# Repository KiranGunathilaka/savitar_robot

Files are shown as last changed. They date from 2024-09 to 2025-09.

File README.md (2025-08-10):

# Savitar Bot
## Compilations of Videos we had taken
[Youtube](https://youtu.be/TuMXFdOwjP4)

## Codebase
[Savitar Robot Codebase](https://github.com/KiranGunathilaka/savitar_robot_codebase)

## Robot Architeture
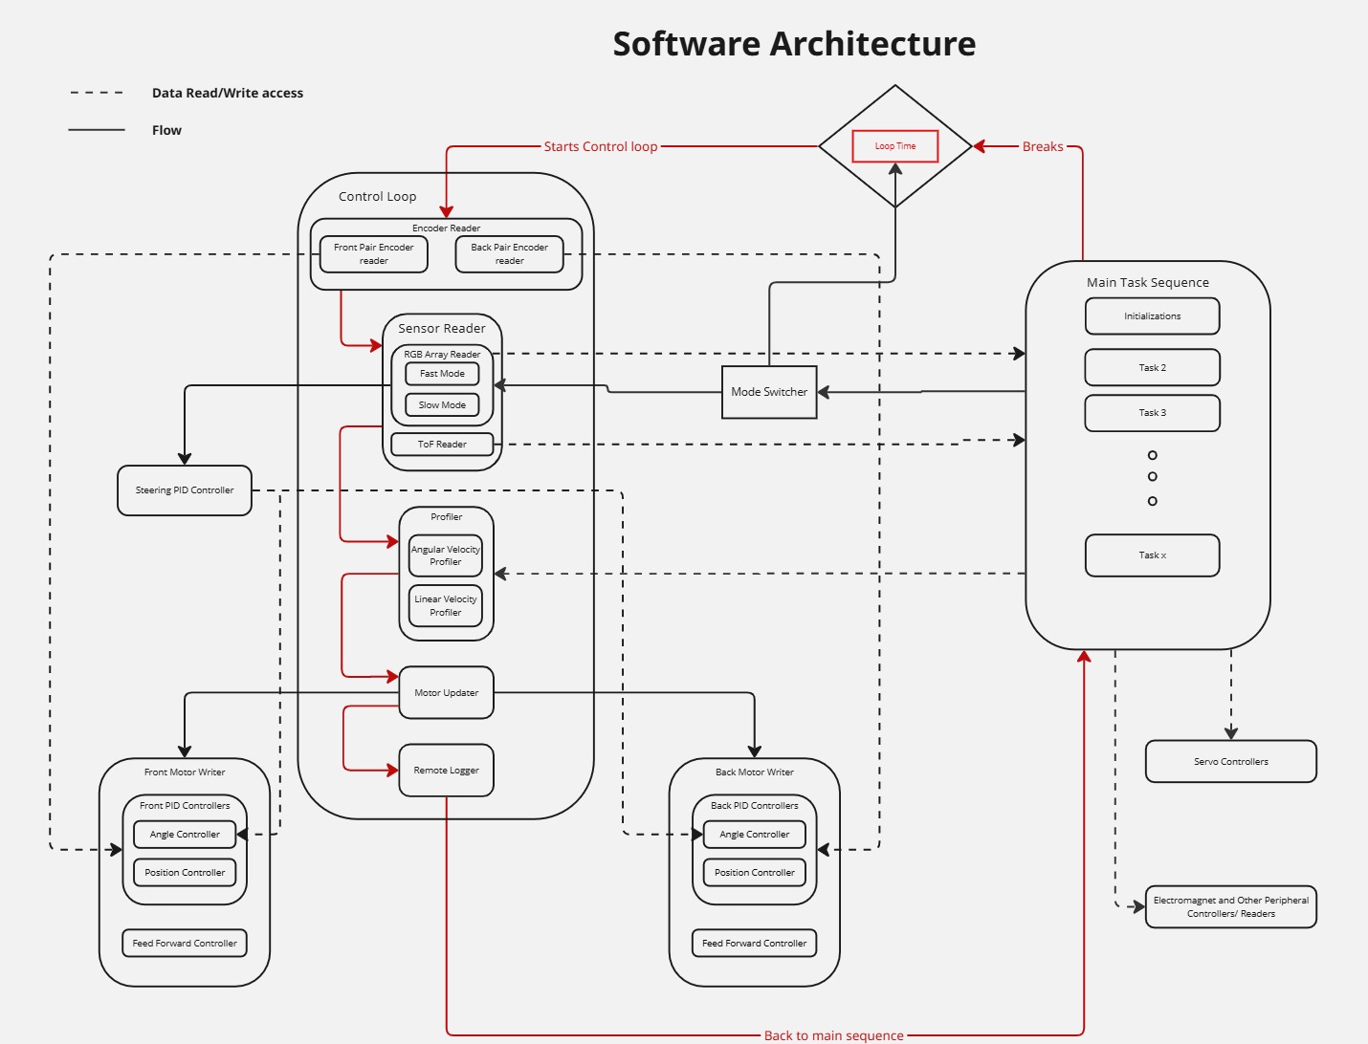
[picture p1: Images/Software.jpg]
Savitar Software

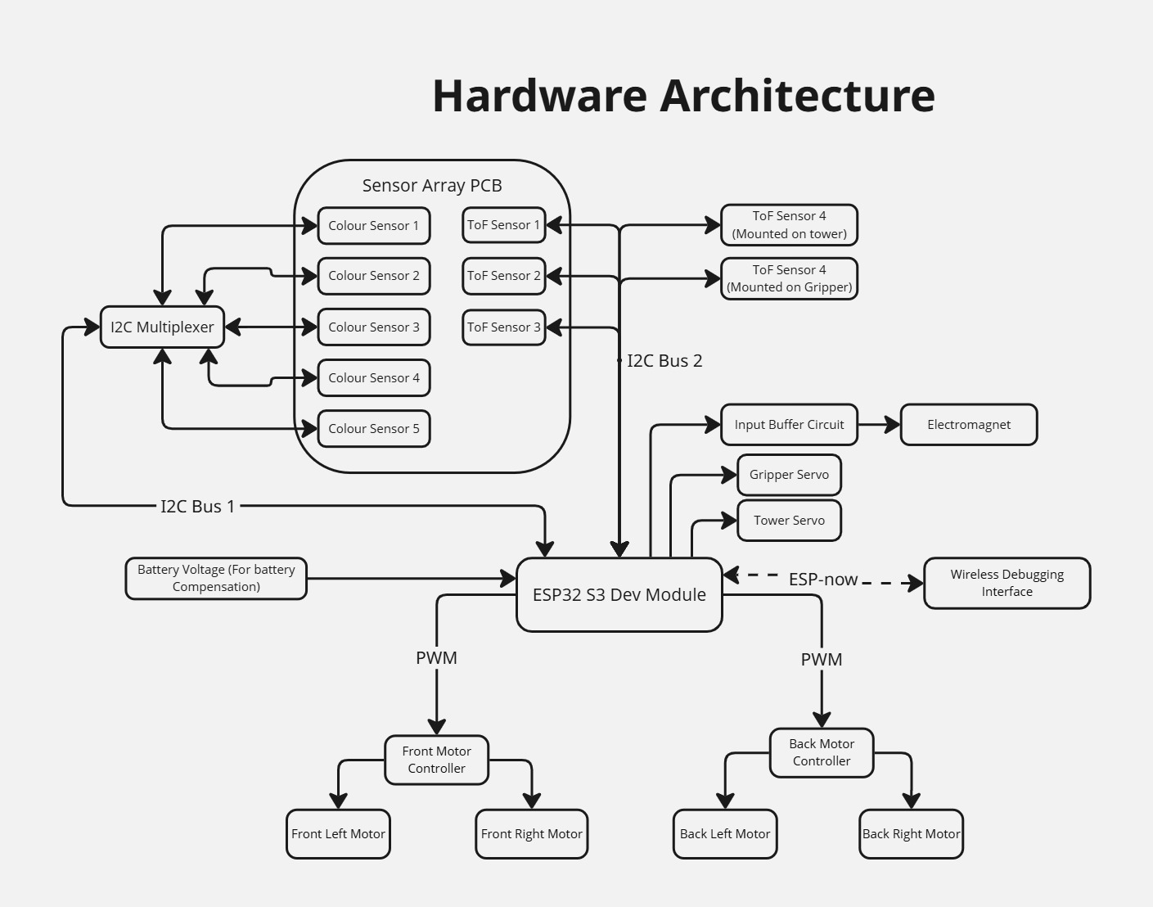
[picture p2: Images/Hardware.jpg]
Savitar Hardware


## Motor Responses
These were done to get the motor function between rps and pwm percentage that need to be fed for feed forward control.
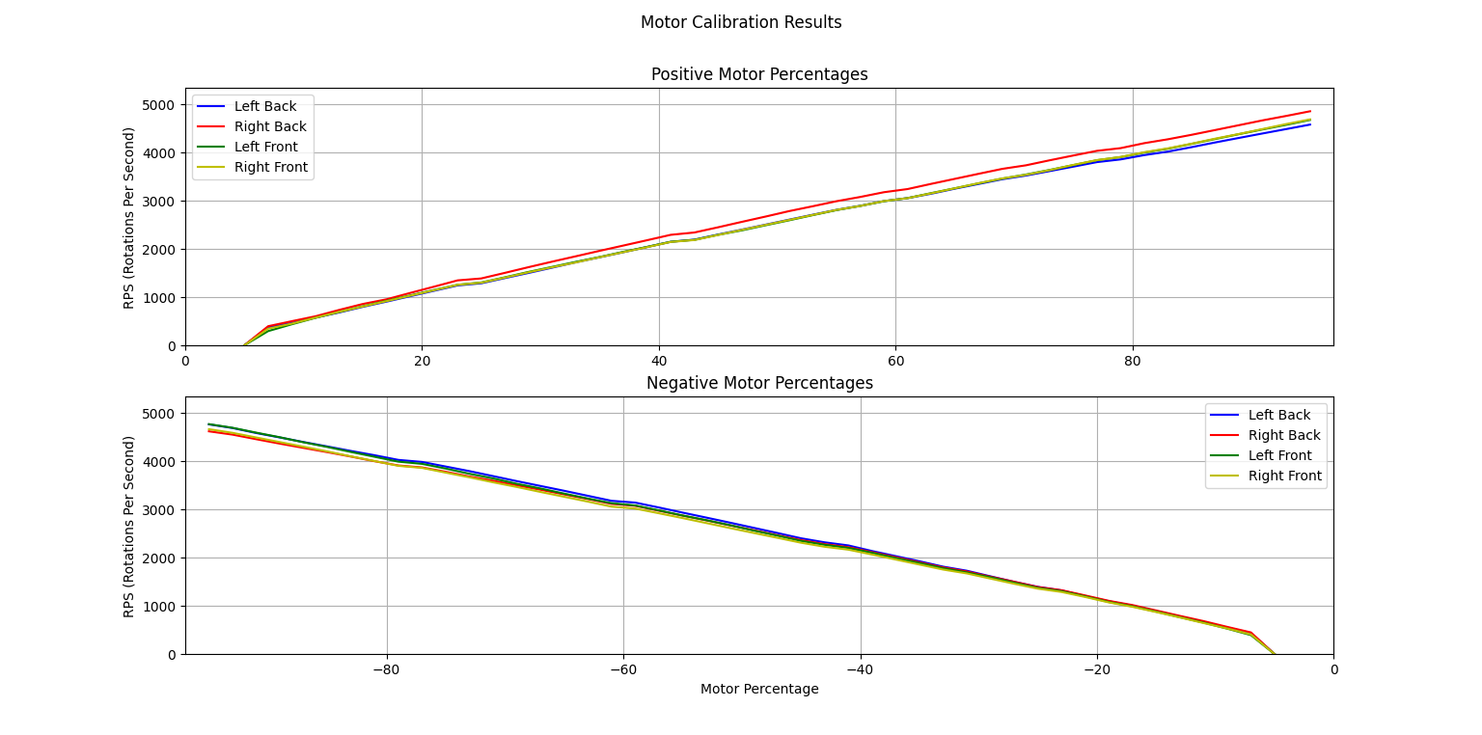
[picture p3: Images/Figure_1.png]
Motor Functions


All the motor logs are available here. 
[Codebase/Test](https://github.com/KiranGunathilaka/savitar_robot_codebase/tree/main/test/motor_logs)

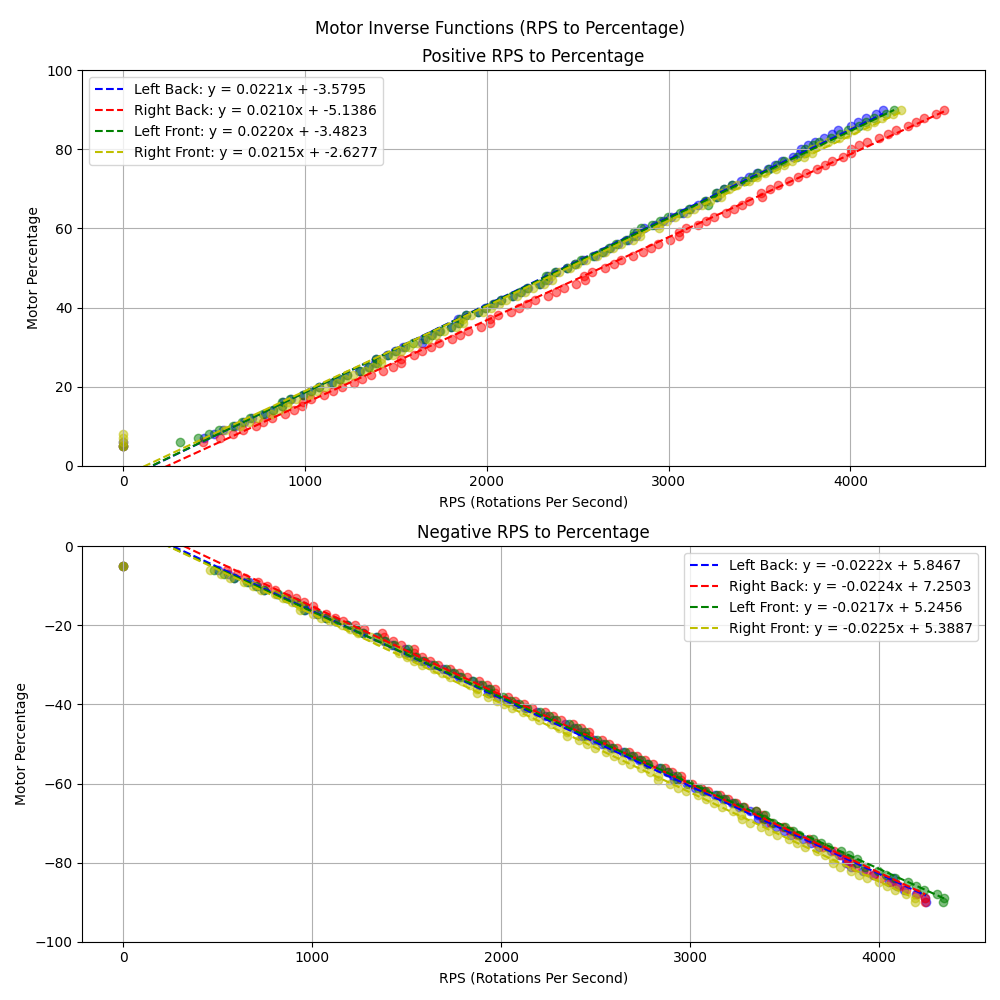
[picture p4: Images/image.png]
Inverse functions


## PCB
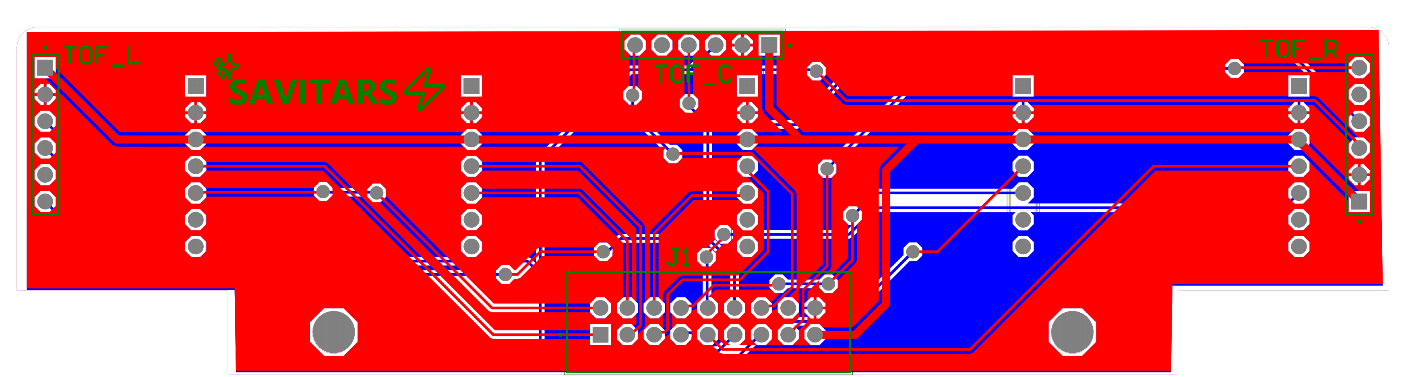
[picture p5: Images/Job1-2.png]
2D View

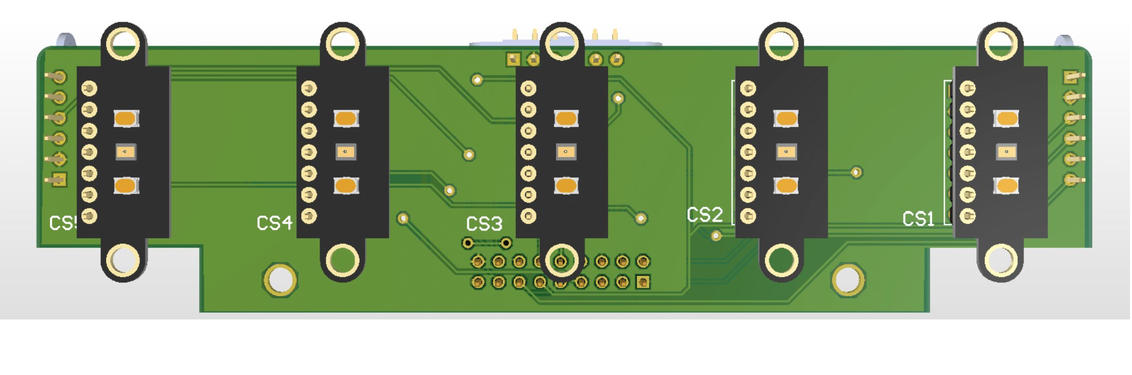
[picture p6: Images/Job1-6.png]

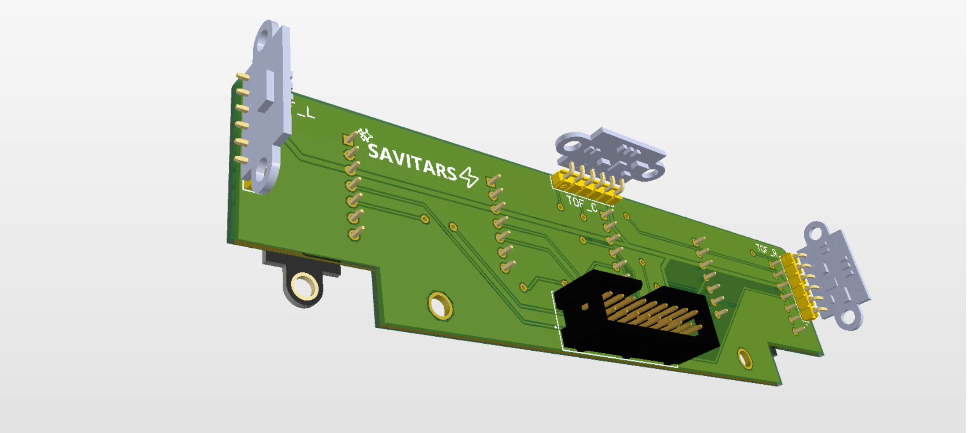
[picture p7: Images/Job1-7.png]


## CAD Designs
### Design V3
Tested and final printed design
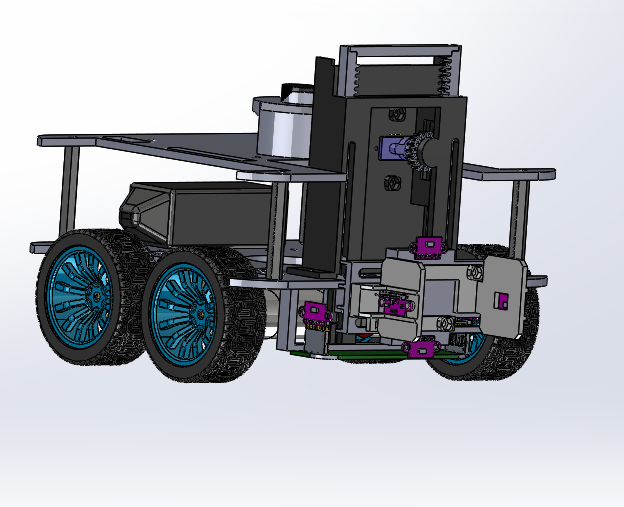
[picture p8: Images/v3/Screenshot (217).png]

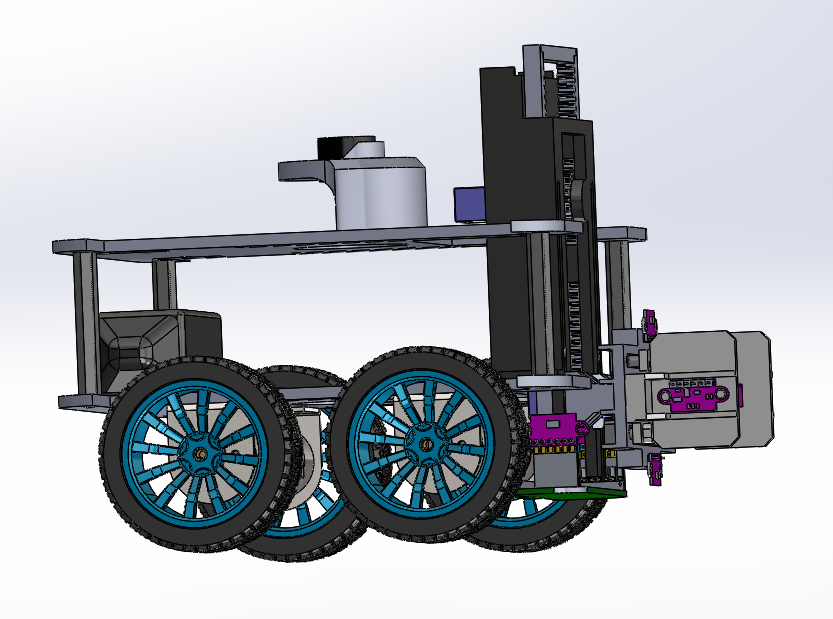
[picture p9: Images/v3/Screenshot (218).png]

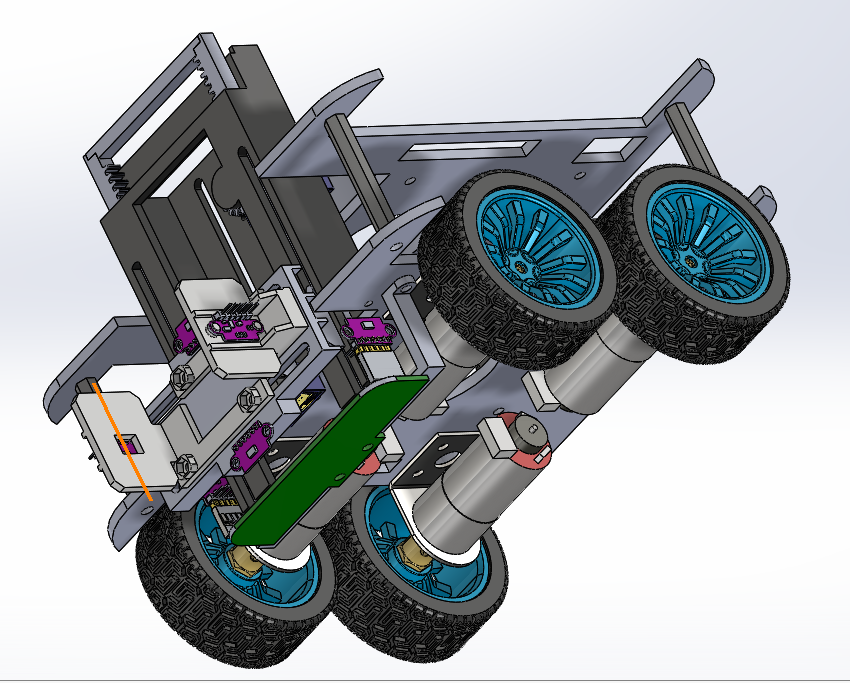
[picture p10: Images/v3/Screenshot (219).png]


## Previous Designs
### Design V1
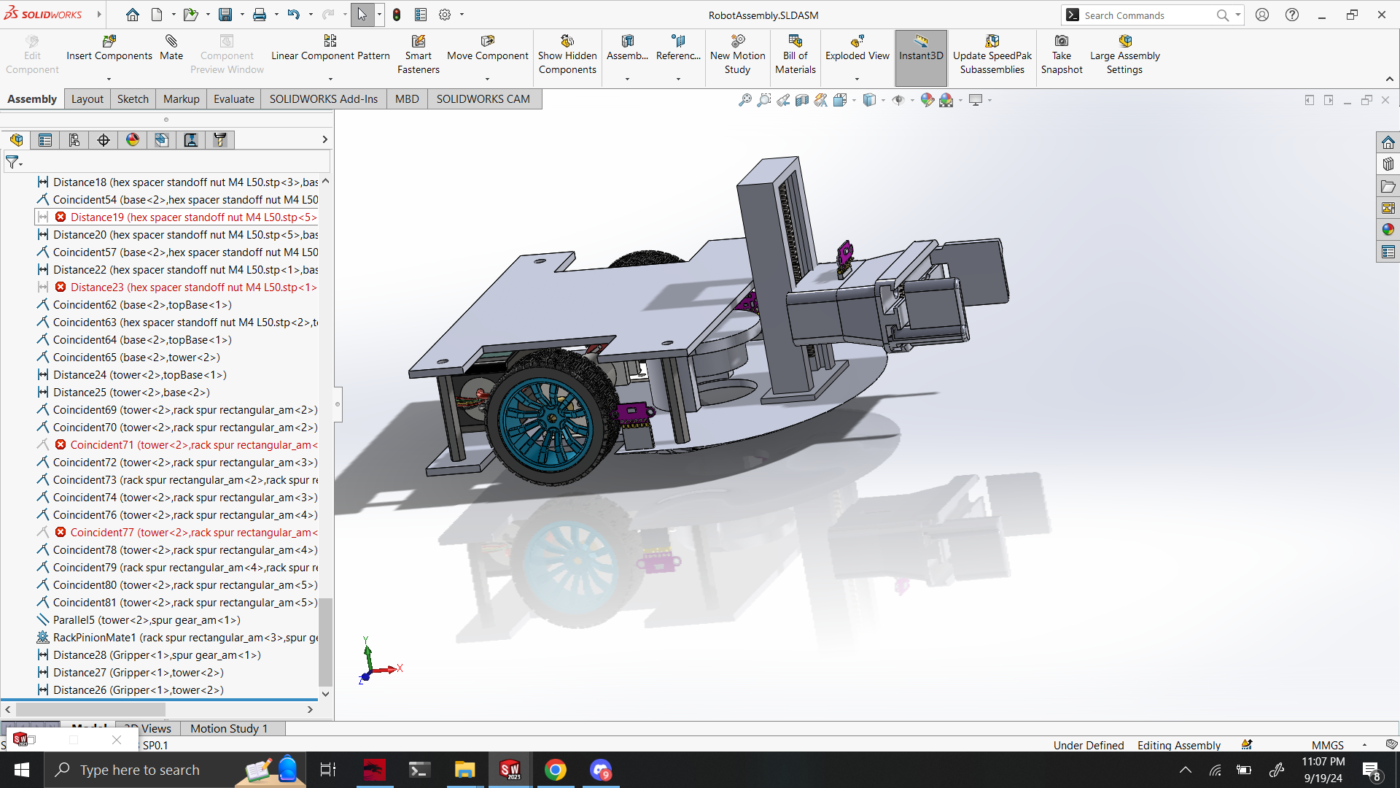
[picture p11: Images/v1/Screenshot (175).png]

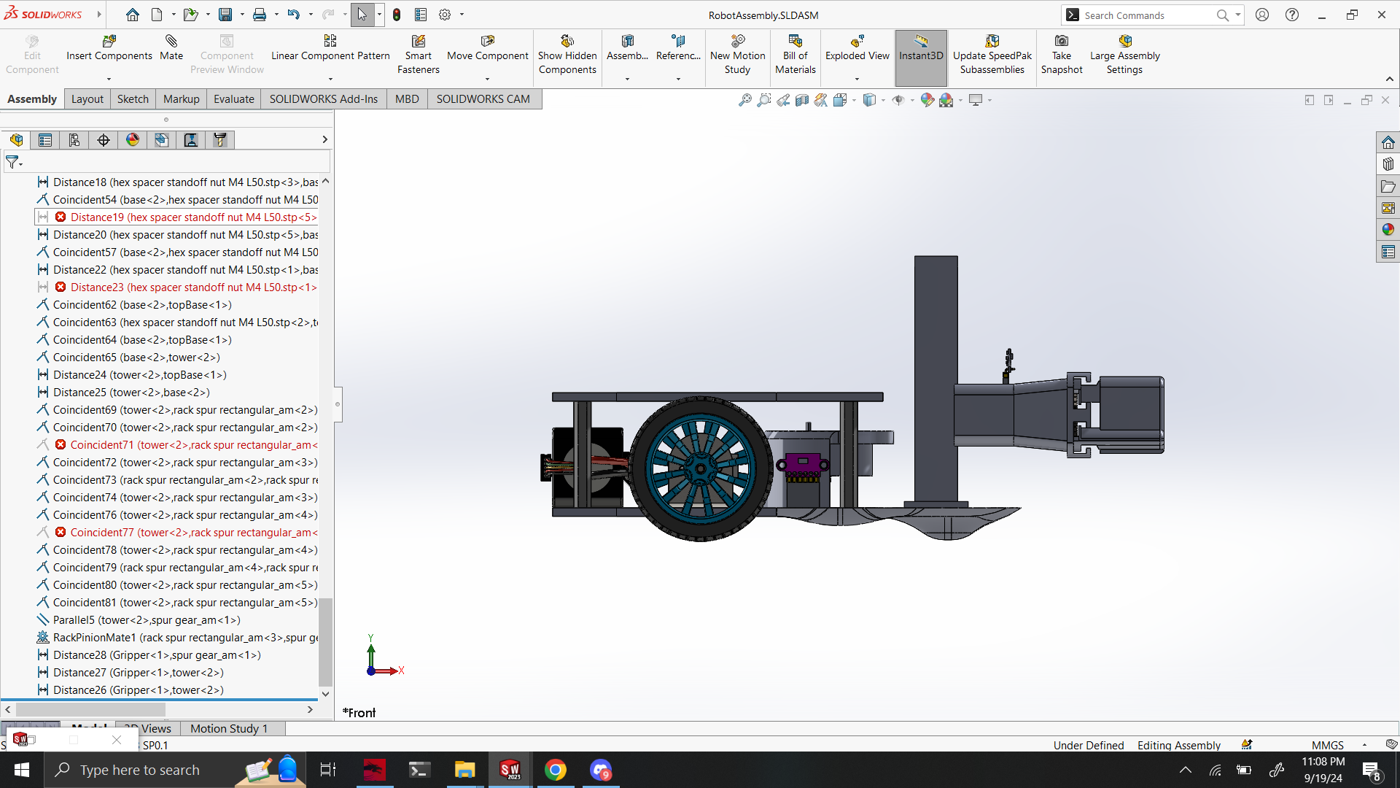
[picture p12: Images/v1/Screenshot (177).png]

### Design V2
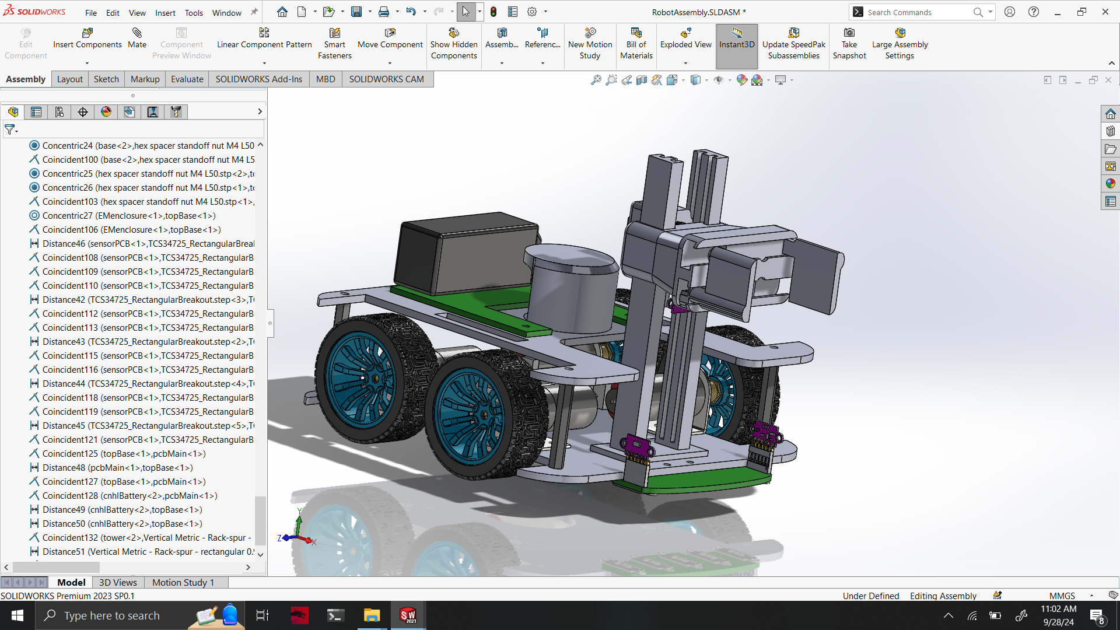
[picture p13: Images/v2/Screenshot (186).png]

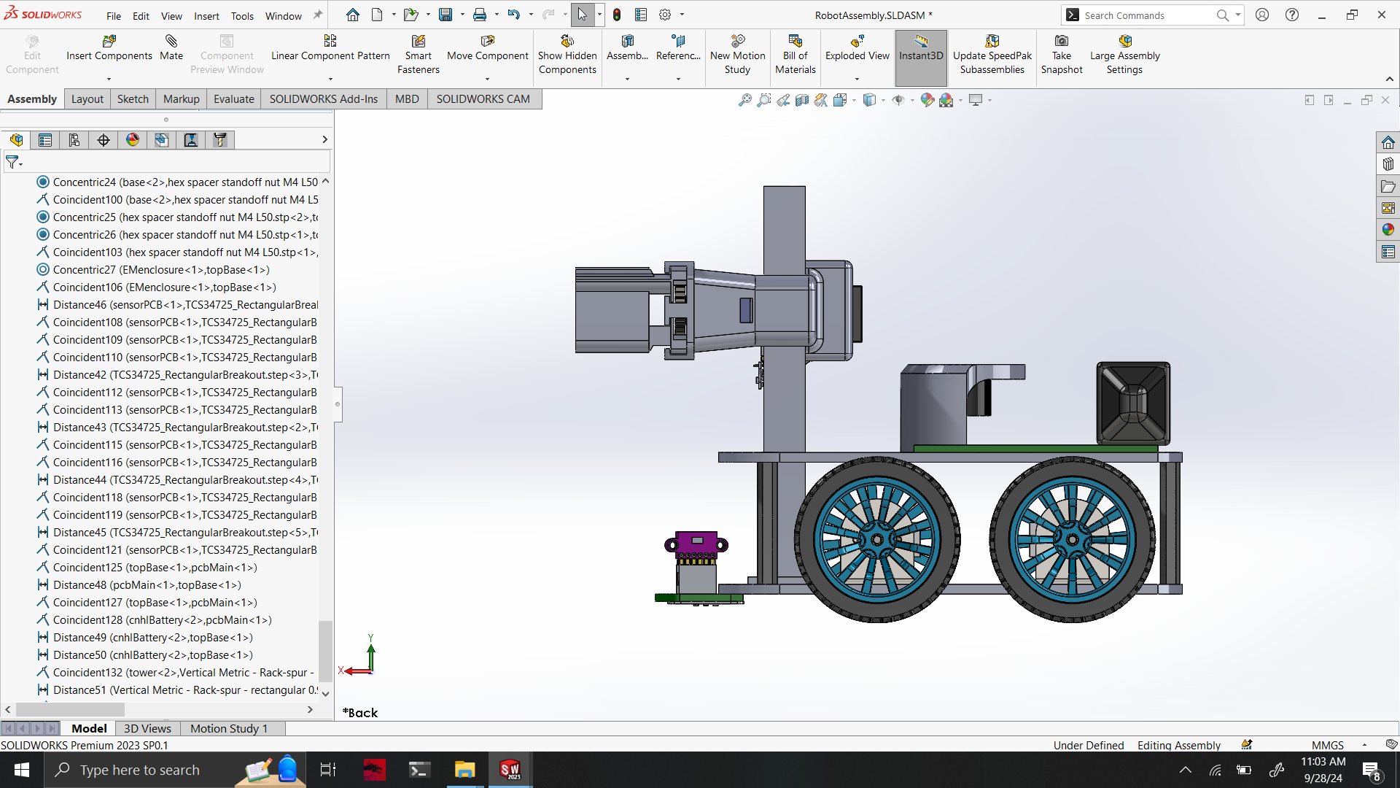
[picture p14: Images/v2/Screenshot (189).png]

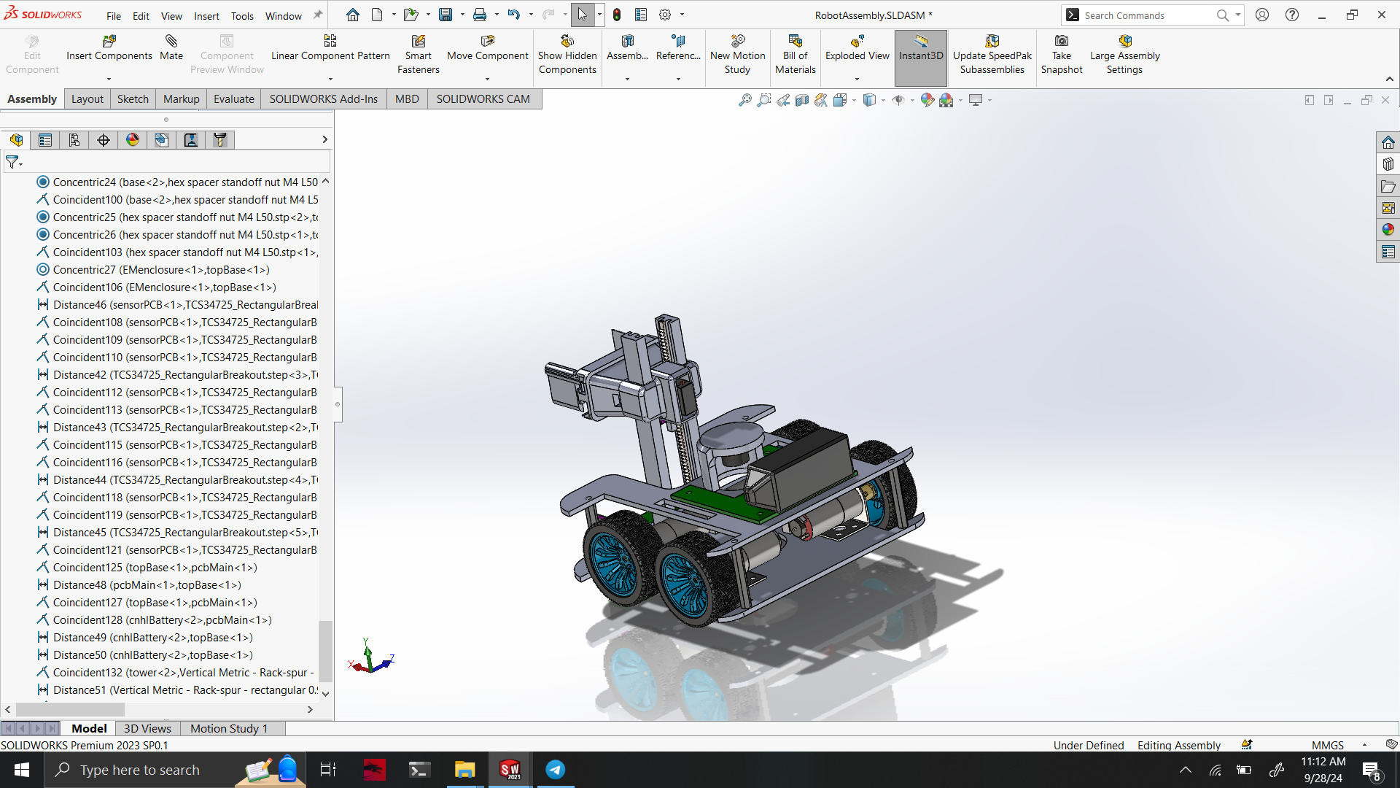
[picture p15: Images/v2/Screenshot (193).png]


### This is the codebase. Full repo is at [Here](https://github.com/KiranGunathilaka/savitar_robot)

<div style="background:#ffffff; color:#111; padding:18px; border-radius:12px; box-shadow:0 2px 10px rgba(0,0,0,.06); font-family:system-ui,-apple-system,Segoe UI,Roboto,Arial,sans-serif; line-height:1.6;">

  <h1 style="margin:0 0 8px;">⚡ Savitar Robot — ESP32-S3 Modular Control Stack</h1>
  <p style="margin:0 0 10px;">
    <strong>Savitar</strong> is a four-motor mobile robot with an <strong>ESP32-S3</strong> brain, color &amp; ToF sensing, a two-pair
    differential drivetrain, and on-the-fly retimed control loops. The firmware is a <strong>PlatformIO</strong> C++ codebase with clean
    separation of <em>motors</em>, <em>motion</em>, <em>sensors</em>, <em>loop scheduling</em>, and <em>telemetry</em>.
  </p>

  <div style="display:flex; gap:12px; flex-wrap:wrap; margin:8px 0 12px;">
    <div style="flex:1; min-width:260px; padding:10px 12px; border:1px solid #e5e7eb; background:#fafafa; border-radius:10px;">
      <strong>Repos</strong>
      <ul style="margin:6px 0 0 18px;">
        <li><a href="https://github.com/KiranGunathilaka/savitar_robot" target="_blank" rel="noopener" style="color:#0b5; text-decoration:none;">github.com</a></li>
        <li>Motor logs: <a href="https://github.com/KiranGunathilaka/savitar_robot_codebase/tree/main/test/motor_logs" target="_blank" rel="noopener">/test/motor_logs</a></li>
      </ul>
    </div>
    <div style="flex:1; min-width:260px; padding:10px 12px; border:1px solid #e5e7eb; background:#fafafa; border-radius:10px;">
      <strong>Video</strong>
      <div style="position:relative; padding-bottom:56.25%; height:0; overflow:hidden; border-radius:8px; border:1px solid #e5e7eb; margin-top:8px;">
        <iframe src="https://www.youtube.com/embed/TuMXFdOwjP4" title="Savitar robot compilation" style="position:absolute; inset:0; width:100%; height:100%; border:0;" allow="accelerometer; autoplay; clipboard-write; encrypted-media; gyroscope; picture-in-picture; web-share" allowfullscreen></iframe>
      </div>
    </div>
  </div>

  <!-- Architecture images -->
  <div style="display:grid; grid-template-columns:repeat(auto-fit,minmax(260px,1fr)); gap:12px; margin:10px 0 12px;">
    <a href="https://raw.githubusercontent.com/KiranGunathilaka/savitar_robot/main/Images/Software.jpg" target="_blank" rel="noopener">
      Software architecture
    </a>
    <a href="https://raw.githubusercontent.com/KiranGunathilaka/savitar_robot/main/Images/Hardware.jpg" target="_blank" rel="noopener">
      Hardware architecture
    </a>
  </div>

  <hr style="border:none; border-top:1px solid #e5e7eb; margin:12px 0;">

  <h2 style="margin:0 0 8px;">🧭 High-Level Design</h2>
  <ul style="margin:0 0 10px 18px;">
    <li><strong>Two independent closed-loop differential pairs</strong> (front &amp; back), each with its own encoder PID and <em>feed-forward</em>, unified by a higher-layer <strong>Motion</strong> controller for v/ω profiles and turning.</li>
    <li><strong>Two line-follow modes</strong> with <em>dynamic control-loop timings</em>:
      <ul style="margin:6px 0 0 18px;">
        <li><strong>FAST_MODE</strong> (black/white tracking) → control loop at <strong>FAST_TICKER</strong> <em>(currently 25&nbsp;ms)</em>.</li>
        <li><strong>SLOW_MODE</strong> (4-color discrimination) → loop at <strong>SLOW_TICKER</strong> <em>(currently 60&nbsp;ms)</em>.</li>
      </ul>
      Mode switching happens on-the-fly: the ticker retimes and the sensor sampler swaps integration windows without rebooting the stack.
    </li>
    <li><strong>ESP-NOW telemetry & tuning</strong>: logs (RGB/ToF/odometry/servo) are broadcast; updated gains/params can be injected from a paired controller.</li>
  </ul>

  <h2 style="margin:0 0 8px;">🧩 Firmware Modules</h2>
    <div style="flex:1; min-width:260px; border:1px solid #e5e7eb; border-radius:10px;">
      <div style="padding:10px 12px; background:#fafafa; border-bottom:1px solid #e5e7eb;"><strong>Motors</strong></div>
      <div style="padding:10px 12px;">
        <ul style="margin:0 0 8px 18px;">
          <li>Maintains <strong>independent PID state</strong> (FWD/ROT) for <em>front</em> and <em>back</em> pairs.</li>
          <li>Applies <strong>feed-forward</strong> models (derived from rps↔PWM calibration) per wheel; accounts for <em>battery sag</em> using measured voltage.</li>
          <li>Combines translational &amp; rotational commands → per-wheel PWM via IN1/IN2/PWM pins (polarity configurable).</li>
        </ul>
        <small style="color:#555;">KP/KD sets present for front/back, with per-wheel polarity and PWM channels.</small>
      </div>
    </div>
    <div style="flex:1; min-width:260px; border:1px solid #e5e7eb; border-radius:10px;">
      <div style="padding:10px 12px; background:#fafafa; border-bottom:1px solid #e5e7eb;"><strong>Motion</strong></div>
      <div style="padding:10px 12px;">
        <ul style="margin:0 0 8px 18px;">
          <li>Holds <strong>linear</strong> and <strong>angular</strong> motion profiles with slew/accel limits.</li>
          <li>Resets/advances profiles each tick; emits unified v/ω setpoints into <em>Motors</em>.</li>
        </ul>
      </div>
    </div>
    <div style="flex:1; min-width:260px; border:1px solid #e5e7eb; border-radius:10px;">
      <div style="padding:10px 12px; background:#fafafa; border-bottom:1px solid #e5e7eb;"><strong>Sensors</strong></div>
      <div style="padding:10px 12px;">
        <ul style="margin:0 0 8px 18px;">
          <li>RGB array via <strong>I²C multiplexer</strong> (TCS34725). Switches integration window based on mode.</li>
          <li>ToF sensors (front/left/right/center-top/center-bottom) with XSHUT pin control and custom addresses.</li>
          <li>Computes steering error using <em>SENSOR_WEIGHTS</em>; classifies <strong>white / red / blue / black / unknown</strong>.</li>
        </ul>
      </div>
    </div>
    <div style="flex:1; min-width:260px; border:1px solid #e5e7eb; border-radius:10px;">
      <div style="padding:10px 12px; background:#fafafa; border-bottom:1px solid #e5e7eb;"><strong>Systick &amp; Robot</strong></div>
      <div style="padding:10px 12px;">
        <ul style="margin:0 0 8px 18px;">
          <li><strong>Systick</strong> ticker calls encoders → sensors → motion → motors at <em>FAST_TICKER</em>/<em>SLOW_TICKER</em>.</li>
          <li><code>enableSlowMode()</code> retimes the loop and flips sensor mode dynamically.</li>
          <li><strong>Robot</strong> orchestrates the flow (e.g., barcode read, maze steps), commanding sensor modes and motion sequence.</li>
        </ul>
      </div>
    </div>
    <div style="flex:1; min-width:260px; border:1px solid #e5e7eb; border-radius:10px;">
      <div style="padding:10px 12px; background:#fafafa; border-bottom:1px solid #e5e7eb;"><strong>Reporting</strong></div>
      <div style="padding:10px 12px;">
        <ul style="margin:0 0 8px 18px;">
          <li>Packs color/ToF/odometry/servo state into ESP-NOW frames to a paired MAC.</li>
          <li>Receives updated gains &amp; parameters for in-field tuning.</li>
        </ul>
      </div>
    </div>

  <h2 style="margin:14px 0 8px;">🔧 Hardware & Config Highlights</h2>
  <div style="display:grid; grid-template-columns:repeat(auto-fit,minmax(260px,1fr)); gap:12px;">
    <div style="border:1px solid #e5e7eb; border-radius:10px; padding:10px 12px;">
      <strong>Drivetrain & Encoders</strong>
      <ul style="margin:6px 0 0 18px;">
        <li><em>4 encoders</em> (LF: 18/8, LB: 3/46, RF: 48/45, RB: 35/36), <em>PULSES_PER_ROTATION</em>=1495.</li>
        <li>Wheel Ø (front/back): 63&nbsp;mm, wheel gap: 189.5&nbsp;mm → <em>DEG_PER_MM_DIFFERENCE</em> derived.</li>
        <li>PWM channels: LF=2, RF=3, LB=4, RB=5; polarity defines forward sense per wheel.</li>
      </ul>
    </div>
    <div style="border:1px solid #e5e7eb; border-radius:10px; padding:10px 12px;">
      <strong>PID & FF</strong>
      <ul style="margin:6px 0 0 18px;">
        <li>Back: FWD KP/KD = 1.0/0.5, ROT KP/KD = 9.18/0.229.</li>
        <li>Front: FWD KP/KD = 1.0/0.5, ROT KP/KD = 9.18/0.229.</li>
        <li>Bias/limits: MIN_BIAS=13, MAX_MOTOR_PERCENT=90, dead-zone floor=5%.</li>
      </ul>
    </div>
    <div style="border:1px solid #e5e7eb; border-radius:10px; padding:10px 12px;">
      <strong>Sensing</strong>
      <ul style="margin:6px 0 0 18px;">
        <li>I²C0: SDA=19, SCL=20 · I²C1: SDA=21, SCL=47.</li>
        <li>RGB sensor (TCS34725) via mux 0x70; fast/slow integration presets.</li>
        <li>ToF XSHUT: R=11, L=13, F=12, CT=10, CB=9 · I²C addrs: 0x30–0x34.</li>
        <li>Steering gains (RGB): KP=14.0, KD=5.5; weights: {2,1,0,-1,-2}.</li>
      </ul>
    </div>
    <div style="border:1px solid #e5e7eb; border-radius:10px; padding:10px 12px;">
      <strong>System & IO</strong>
      <ul style="margin:6px 0 0 18px;">
        <li>FAST_TICKER=0.025&nbsp;s · SLOW_TICKER=0.060&nbsp;s (retimed by mode).</li>
        <li>Servos: gripper=38 (0→140°), lift=14; EM pin=41; user switch=7; LED=0.</li>
        <li>ESP-NOW peer MAC baked in (<code>broadcastAddress</code>).</li>
      </ul>
    </div>
  </div>

  <h2 style="margin:14px 0 8px;">📈 Motor Characterization & Feed-Forward</h2>
  <p style="margin:0 0 8px;">Each motor was profiled to establish rps↔PWM relationships for feed-forward terms; this reduces PID effort and keeps response consistent across loads/voltage.</p>
  <div style="display:grid; grid-template-columns:repeat(auto-fit,minmax(260px,1fr)); gap:12px;">
    <a href="https://raw.githubusercontent.com/KiranGunathilaka/savitar_robot/main/Images/Figure_1.png" target="_blank" rel="noopener">
      Motor functions (rps vs PWM)
    </a>
    <a href="https://raw.githubusercontent.com/KiranGunathilaka/savitar_robot/main/Images/image.png" target="_blank" rel="noopener">
      Inverse functions
    </a>
  </div>
  <p style="margin:6px 0 12px;">Logs & CSVs for these curves are available in <a href="https://github.com/KiranGunathilaka/savitar_robot_codebase/tree/main/test/motor_logs" target="_blank" rel="noopener">test/motor_logs</a>.</p>

  <h2 style="margin:14px 0 8px;">🛠️ Build & Calibrate (high-level)</h2>
  <ol style="margin:0 0 10px 18px;">
    <li>Open the repo in <strong>PlatformIO</strong> and select the ESP32-S3 environment.</li>
    <li>Wire up encoders/motors/sensors per <em>configuration header</em> (pins & addresses above).</li>
    <li>Upload, verify encoder counts, then run motor characterization if you change the drivetrain.</li>
    <li>Calibrate RGB sensors (white/black &amp; colors) and ToF offsets; save constants.</li>
    <li>Test <strong>FAST_MODE</strong> and <strong>SLOW_MODE</strong> switching; check loop timing histograms in ESP-NOW logs.</li>
  </ol>

  <h2 style="margin:0 0 8px;">🚀 Notes & Next Steps</h2>
  <ul style="margin:0 0 4px 18px;">
    <li>Add loop-overrun counters and a small timing histogram to the logger.</li>
    <li>Store per-mode PID/FF presets with bumpless transfer on retime.</li>
    <li>Extend obstacle handling (wall following & ToF fusion) with a small EKF for heading drift.</li>
  </ul>

</div>

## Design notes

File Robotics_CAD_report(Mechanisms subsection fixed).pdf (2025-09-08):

# Initial Prototype of the Mobile Robot-CAD drawings

### Group name : Savitars

Group Members : K.L.Gunathilaka (220197E), I.J.M.J. Sadaruwan(220542J), L.P.P. Pahasara (220439B), T.P.N.S. Peiris (220454P), M.P.L. Budvin (220077L)

## 1 Overview

This report outlines the preliminary design of our robotic system .The core components such as motors,sensors,and modules will be taken from existing manufacturers, while the remaining structural and functional elements are designed by ourselves.To facilitate the development process, CAD drawings have been created to visualize the overall mechanical design and dimensions of the robot. To ensure flexibility and efficieny,we are planning to design a custom PCB for the system therefore the specific placement of motor drivers and microcontrollers are not specifically mentioned in this report.

## 2 Robot Layout

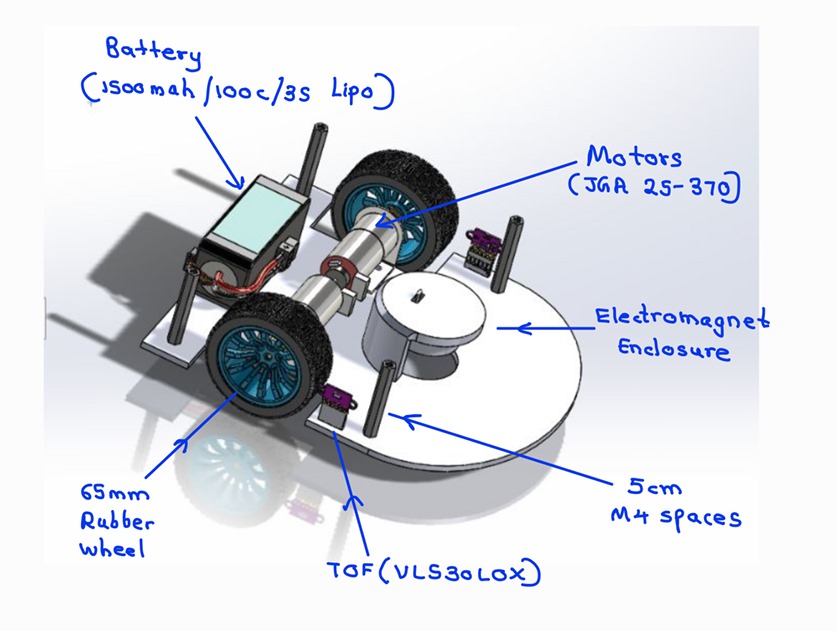
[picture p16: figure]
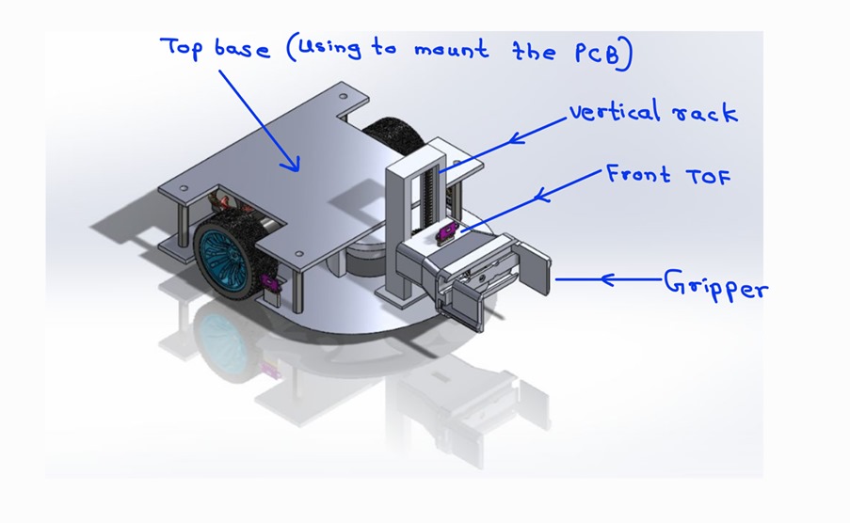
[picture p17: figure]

Figure 1 | Figure 2

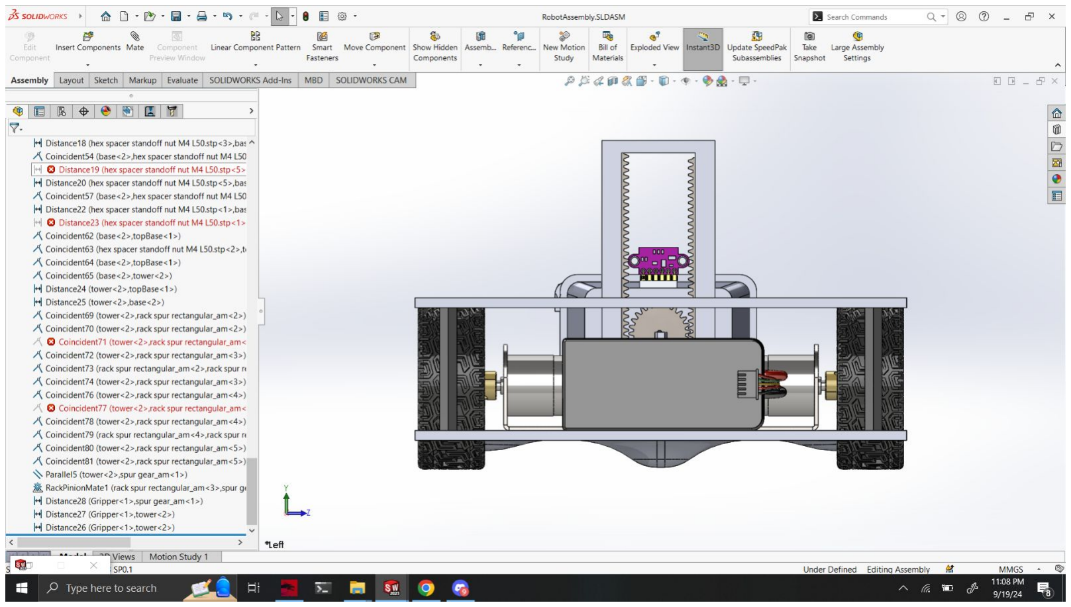
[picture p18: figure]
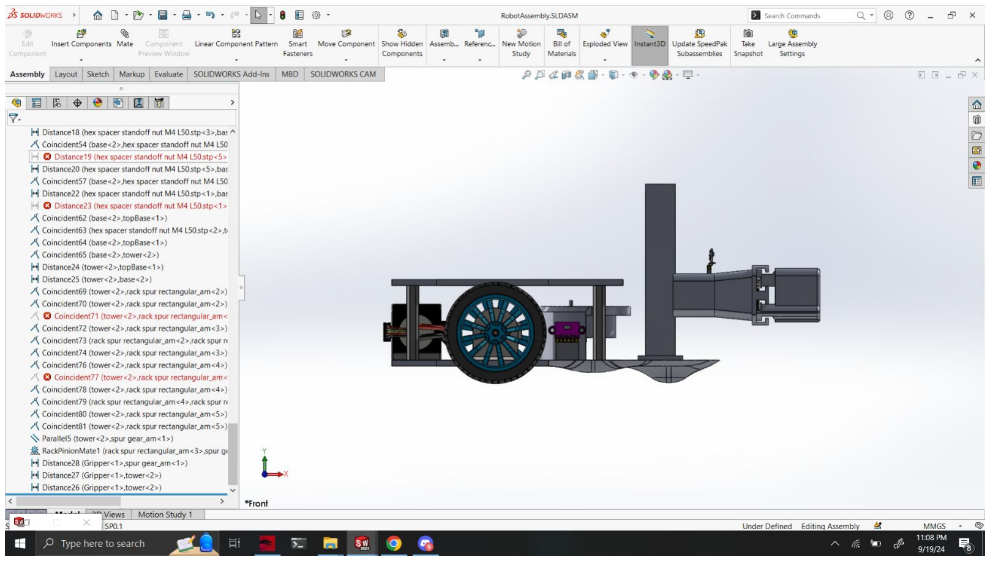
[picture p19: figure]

Figure 3: Front View | Figure 4: Side View

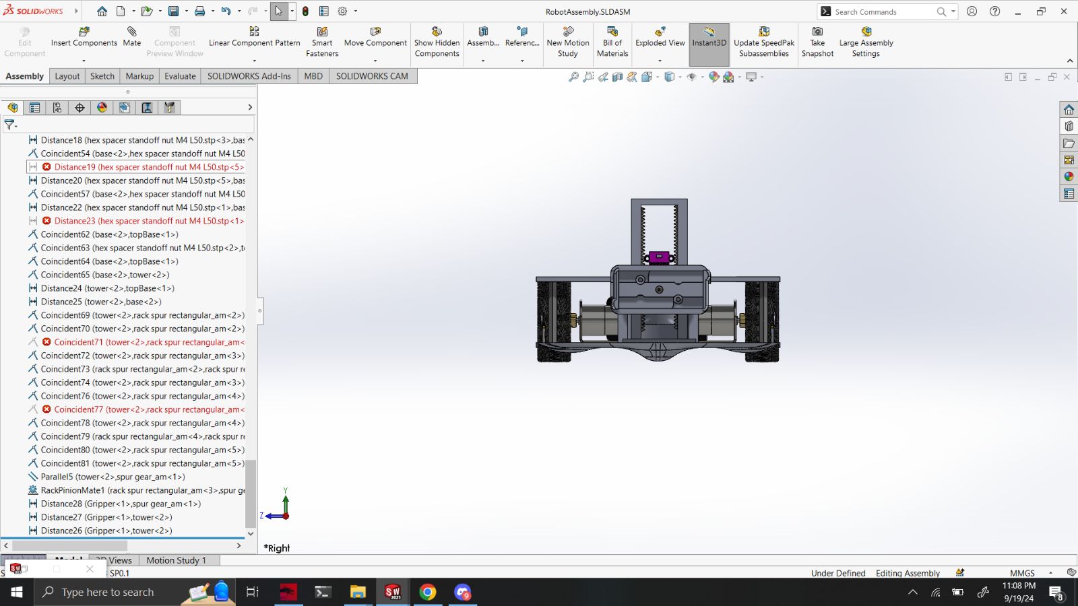
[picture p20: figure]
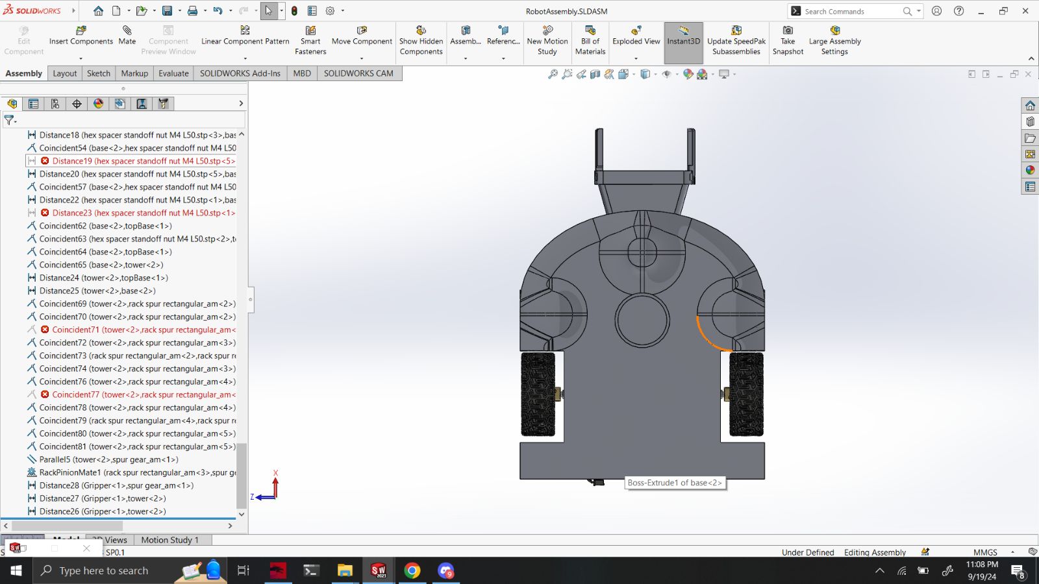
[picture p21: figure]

Figure 5: Rear View | Figure 6: Bottom Veiw

## 3 Actuator Mechanisms

### 3.1 Gripper Mechanism

The robot will utilize rack and pinion mechanism for its parallel gripper.The gripper has a very small thickness of only 4mm, enabling it to navigate tight spaces.With a maximum opening of 6.9cm, the gripper can grasp the 5cm box which is ideal for our purposes. Even while holding the box the combined width of the gripper arm (4mm) and the grasped box (5cm) adds up to 5.8cm, leaving enough space to pass through the 7cm x 7cm chamber opening.

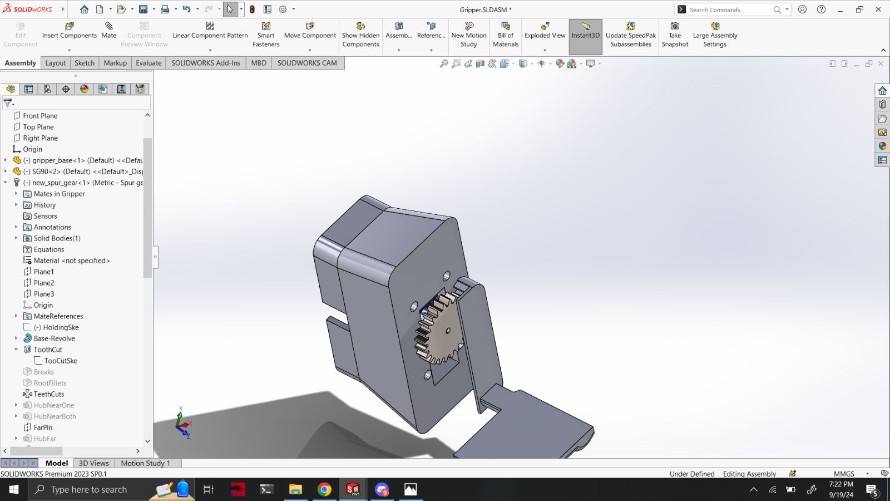
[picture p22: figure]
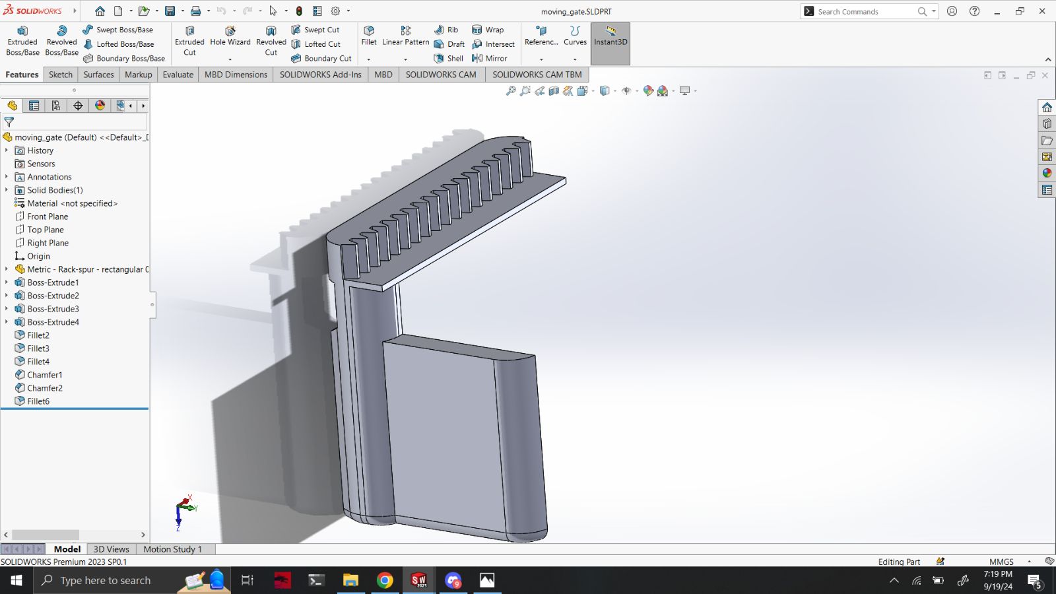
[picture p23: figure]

(a) Pinion | (b) Rack

### 3.2 Vertical rack and pinion mechanism

### 3.2.1 Box Height Detection

The gripper has a vertical range of motion, allowing it to move up and down to identify boxes of 5cm, 10cm, and 15cm.This gripper has a vertical range of 2.5cm to 12.5cm.

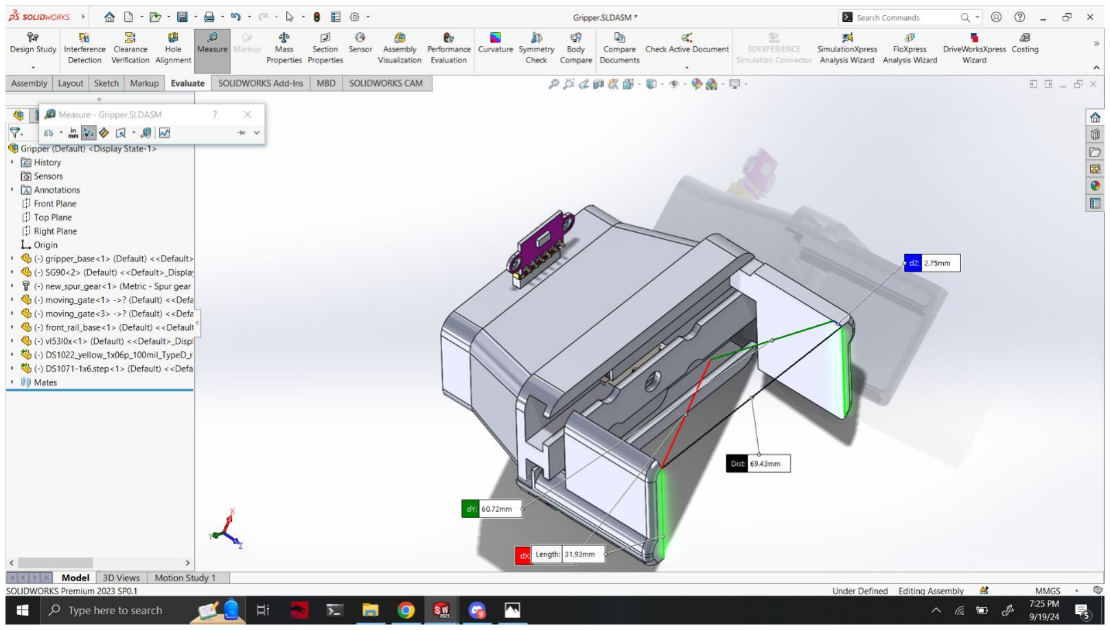
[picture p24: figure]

Figure 8: Front ToF mounted on the gripper for detecting height

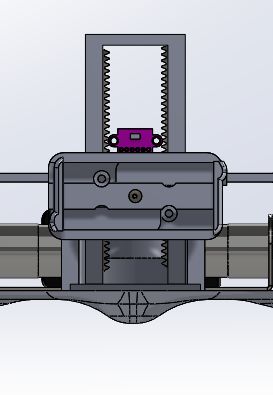
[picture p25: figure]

Figure 9: Gripper is free to slide on the vertical rack

### 3.2.2 Moving Boxes Vertically

The robot will pick up the boxes and lift them 5cm high using the gripper before placing them in the destination.

### 3.3 Coin Drop Mechanism

The robot will use a electromagnet to securely hold the coin.Once the robot reaches the designated drop point, a KK P20/15 3kg solenoid (selected locally available electromagnet) will be de-energized, releasing the coin from the gripper’s magnetic hold. This controlled release ensures that the coin falls gently and accurately at the intended location.

## 4 Robot Base

The base is positioned 11mm above the ground.During line-following and other tasks, only the front center of the base makes contact with the ground, providing precise control.To enhance stability and prevent tipping on uneven terrain, two additional contact points are located on the sides of the base, each measuring 8mm.These side contact points ensure that the robot remains firmly grounded.We have already tested a similar base for another application in the past.

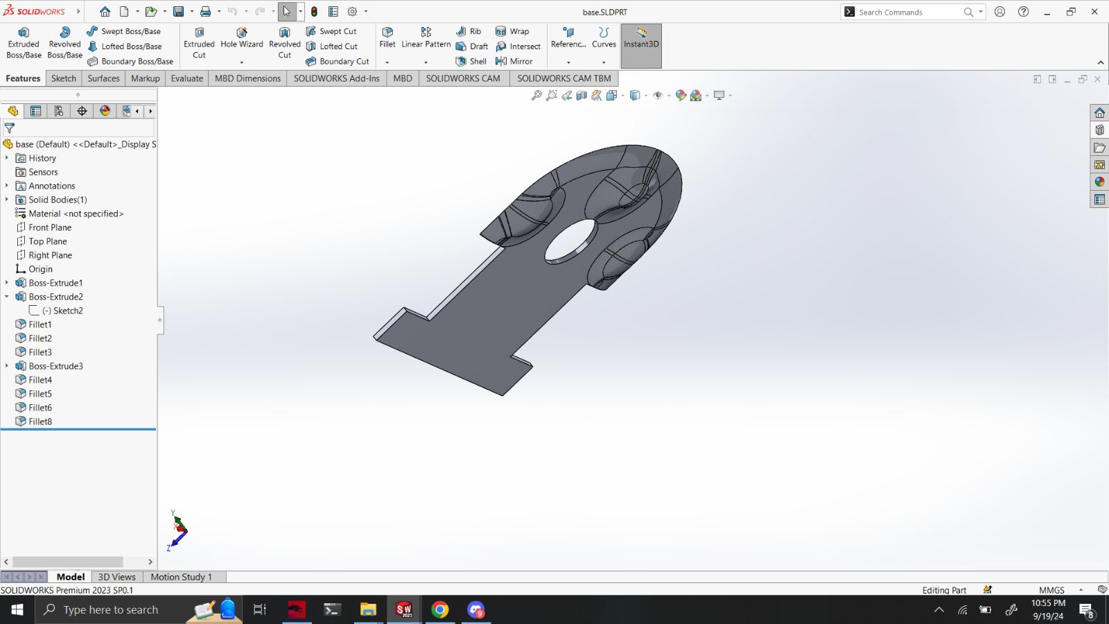
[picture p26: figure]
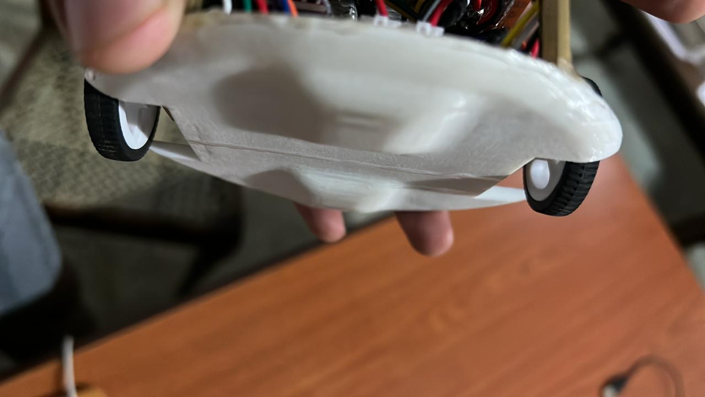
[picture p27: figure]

Figure 10 | Figure 11

## 5 Actuators

### 5.1 MG90 Servo Motor

The MG90 servo motor will be used to drive the gripper across the vertical rack. MG90 was specifically selected for this purpose because it has torque of 2.2kg/cm and will be capable of lifting both the boxes and the gripper

### 5.2 SG90 Servor Motor

SG90 servo will be used to open and close robot’s parralel gripper arms throuth the rack and pinion mechanism. We have selected this servo as this appication does not require much torque as the servo needed for hoisting the gripper and the boxes.

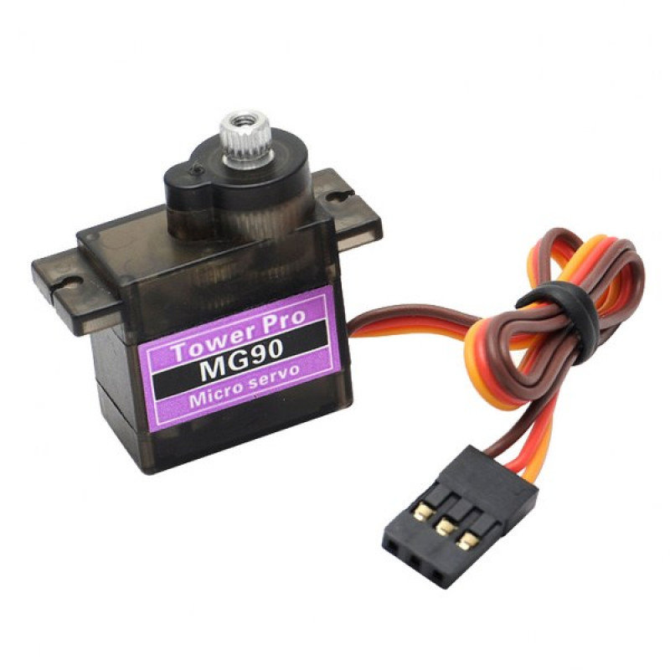
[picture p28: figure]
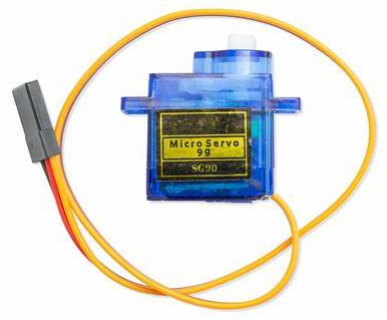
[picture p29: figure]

Figure 12: MG90 | Figure 13: SG90

Both the servos might need to be modified to do the 360 degree rotation by removing the potentiometers inside. Because simple 90 degree rotation to either direction will not rotate the spur gears through the entire length of both our vertical and horizontal racks.

### 5.3 JGA 25-370 DC motor with encoders

For applications demanding higher power and continuous motion, the JGA 25-370 brushed DC motor was chosen. Its robust design and ability to deliver substantial torque make it suitable for driving wheels or powering heavy-duty components.

Figure 14: JGA 25-370 DC Motor

## 6 Sensors and their mounting positions

### 6.1 TCS34725 - Colour Sensor Array

For the line following task, we will construct and place a color sensor array on the front curved line of the robot. This array will consist of 5 TCS34725 color sensors strategically positioned at 3cm intervals.

### 6.2 VLS30L0X - ToF

We will incorporate three Time-of-Flight sensors. One ToF sensor will be strategically placed on the gripper. Additionally, two ToF sensors will be mounted on the base of the robot, providing valuable information for detecting nearby walls when moving in uneven terrain.

## 7 Conclusion

In conclusion, this report has outlined the preliminary design our robot, highlighting key components such as mechanisms, sensors, actuators, and the chassy. The robot’s rack and pinion-driven gripper, vertical lifting mechanism, and coin drop system are designed for efficient object handling in tight spaces. Actuators like the MG90 and SG90 servos, along with the JGA 25-370 DC motor, ensure smooth operation and movement. Additionally, the placement of color and Time-of-Flight sensors enhances environmental interaction. This design forms a solid foundation for further development, with flexibility for custom PCB integration and future testing.

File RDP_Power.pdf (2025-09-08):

# Robotic Design Project Power Requirement Analysis

Team Savitars

K.L.Gunathilaka (220197E), I.J.M.J. Sadaruwan(220542J), L.P.P. Pahasara (220439B), T.P.N.S. Peiris (220454P), M.P.L. Budvin (220077L)

September 21, 2024

## 1 Current requirements of each component

Component | Current Re-quirement | Qt. | Maximum | Operational | Notes
JGA 25-370 Motors | 1800 mA (Stall Cur-rent) 450mA (Opera-tional) | 2 | 3600 mA | 900mA | Motor specifications and current ratings (https://www.aliexpress.com/item/4001314473291.html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)
ESP32-S3 SoC (WiFi disabled mode) | 110 mA | 1 | 110 mA | 110mA | This is the tested value for De-vBoard. Datasheet mentioned that the modem-off mode with 80MHz clock should consume about 50mA. (Might be this when using the bare ESP SoC Module for the final robot)
TCS34725 Colour Sensor Module with 2 SMD White LEDs | 4 mA | 5 | 20 mA | 20mA | Tested Value
VL530L0x ToF Sensor | 20 mA | 3 | 60mA | 60mA | Tested and mentioned in the datasheet
Tower Pro MG90s Servo | 800mA (Stall Cur-rent) 250mA (Opera-tional) | 1 | 800mA | 250mA | Idle : 10mA, Operational: 120-250mA (https://protosupplies.com/product/servo-motor-micro-mg90s-continuous-rotation/) (Haven’t verified as not in possession at the moment. Manufacturer datasheet doesn’t mention current ratings)

Tower Pro SG90 Servo | 300mA (Stall Cur-rent) | 1 | 300mA | 250mA | Idle : 10mA, Operational: 100-250mA (https://protosupplies.com/product/servo-motor-micro-mg90s-continuous-rotation/) (Haven’t verified as not in possession at the moment. Manufacturer datasheet doesn’t mention current ratings)
KK P20/15 2.5kg 5V DC Lifting Solenoid | 220mA (Max) | 1 | 220 mA | 220mA | Digikey (https://mm.digikey.com/Volume0/opasdata/d220001/medias/docus/836/3872_Web.pdf)
TCA9548A I2C Multiplexer IC | 20mA | 1 | 20 mA | 20mA | Texas Instruments (https://www.ti.com/lit/ds/symlink/tca9548a.pdf)
TB6612FNG Dual Motor Driver IC | 2.2mA | 1 | 2.2 mA | 2.2mA | SparkFun (https://www.sparkfun.com/datasheets/Robotics/TB6612FNG.pdf)
GY-271 Magne-tometer Module (with QMC5883L) | 3 µA | 1 | 0 | 0 | datasheet (http://wiki.sunfounder.cc/images/7/72/QMC5883L-Datasheet-1.0.pdf)
Magnetic Encoders | 3.5mA | 2 | 7mA | 7mA | Tested
Total | | | 5200mA | 1840mA | Absolute maximum possible cur-rent and operational maximum current that can be drawn

The power source should be capable of delivering a peak current of 5.2A at any given moment. However, it’s important to note that under typical operating conditions, the actual current drawn by the motors and servos will not exceed approximately 1.9A . This design ensures a safety margin for sudden power demands while maintaining efficient operation during normal use.

## 2 Voltage requirements of the robot

All the sensors and control units can function with a voltage less 3.7 (Nominal voltage of Li-Po cell). But the actuators like servos require a typical voltage of 5V and the DC motor require a voltage higher than 6V to function in it’s best performence. So a 2 series Li-Po or Lithium Ion battery cell configuration would be most suitable for our robot.

## 3 Suitability of acquired power source

As we already have a 2P CNHL 3S(11.1V) 100C Li-Po 1500mAh Battery pack we acquired for another application, we will analyze the suitability of that battery for our robot.

The maximum possible current the battery can supply (Imax) is,

Imax = C × Capacity = 100 × 1.5 A = 150 A

The maximum current requirement is satisfied since:

Imax > 5.2 A

The operational duration (T) of the battery, without discharging below 80% of its capacity is,

T =

Capacity × 0.8

Ioperational

=

1500 mAh × 0.8
1840 mA ≈ 0.652 h ≈ 39 minutes

As the supply voltage(11.1V) is higher than that of the highest required voltage(6V) this battery pack will be suitable for suppling power to the system via a voltage regulator or step down circuitry.

## 4 Power Source Alternatives

4.1 2S Lithium Polymer (Li-Po) Battery Pack(7.4

- Pros:

– Possibility of being lighter in terms of weight compared to 3S

– Lower voltage, potentially reducing the need for voltage regulation

– Still provides sufficient voltage for most components

- Cons:

– Might not provide enough voltage for optimal DC motor performance when discharged to some extent.

– Expensive and most of the locally available 2S packs are heavier compared to the already available 3S pack.

### 4.2 Li-ion 18650 Battery Pack (2S2P or 3S2P configuration

- Pros:

– Generally cheaper than Li-Po batteries

– More stable and safer than Li-Po

– Easy to replace individual cells if needed

- Cons:

– Lower discharge rates compared to Li-Po

– Heavier than equivalent capacity Li-Po packs

– May require a custom battery holder or casing

– Larger form factor will take much room from the robot

4.3 10-cell NiMH Pack (12V nominal)

- Pros:

– Very safe and stable

– Can handle high discharge rates

– Often cheaper than Li-Po or Li-ion

- Cons:

– Much heavier than Li-Po or Li-ion for equivalent capacity

– Lower energy density, resulting in shorter run times or larger battery size

– Prone to self-discharge and memory effect

4.4 20000mAh USB power bank with 5V output

- Pros:

– Easily rechargeable with standard USB chargers

– Safe to use

– Can potentially power the system directly at 5V

- Cons:

– May require additional circuitry to step up voltage for motors

– Limited maximum current output compared to dedicated battery packs

– Bulkier than a custom battery solution

## 5 Notes

Although the chosen battery pack somewhat exceeds the power requirements of our current application interms of the discharge rate, its integration offers several advantages:

- Minimal weight impact: At approximately 143g, the battery’s lightweight design ensures negligible effect on the robot’s overall functionality compared to other 2S Li-Po battery packs available on the market.
- Cost-effectiveness: Utilizing this existing resource allows for more efficient allocation of our budget.

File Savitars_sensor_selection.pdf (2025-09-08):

## EN2533 - Robot Design and Competition Sensor Selection and Justification

Group Name | : Savitars
Group Members | : K.L.Gunathilaka (220197E), I.J.M.J. Sandaruwan (220542J), L.P.P. Pehesara (220439B),
| T.P.N.S. Peiris (220454P), M.P.L. Budvin (220077L)

## 1 Chosen sensors for each specific sub-tasks

Task | Task Description | Sensor
Task 1 | Crossing lines of varying widths and reading the barcode | TCS34725 Dual Mount Colour Sensor x5, Quadrature Encoders
Task 2 | Grabs a virtual box and moves it to a specific checkpoint | TCS34725 Dual Mount Colour Sensor x5, Quadrature Encoders, VL530L0x(TOF)
Task 3 | Following a path marked with a specific colour | TCS34725 Dual Mount Colour Sensor x5
Task 4 | Following a path marked with dotted lines | TCS34725 Dual Mount Colour Sensor x5
Task 5 | Navigation through a door-like portal | VL530L0x(TOF)
Task 6 | Rearranging the boxes of different heights into a specific order | VL530L0x(TOF)
Task 7 | Grabs a small box and inserts it into a larger box’s hole | Quadrature Encoder Readings
Task 8 | Navigation through uneven terrain and placing a coin on a magnetized spot | GY-271 (HMC5883L) Magne-tometer, VL530L0x ToF x3

Table 1: Task Descriptions and Associated Sensors

## 2 Reasons for selecting above sensors

### 2.1 TCS34725 Colour Sensor

When selecting a sensor for the line-following task of this challenge, we evaluated and tested out several options, including the TCRT5000 IR emitter and phototransistor, standalone IR emitters and receivers available in the local market (without specific model names), and the TCS34725 color sensor.

When choosing the sensor for this main sub task, we had 3 concerns.

1. Capability of providing a distinguishable reading for White, Black, Red and Blue lines.
2. Capability of taking accurate readings while having enough ground clearance as we have to navigate through the rough terrain presented in the last sub-task.
3. Reducing the cost and capability of rapid prototyping.

If we are to use IR sensors, then the the IR sensors we are choosing must be capable of distinguishing at least 3 colours using different IR analog read values. When testing the TCRT5000 IR emitter and receiver, we found that it wasn’t capable of differentiating colors, even the white and black, if the sensor’s ground clearance exceeded about 2mm. The standalone IR emitter LED and phototransistor showed slight improvements in detecting color variations, but their performance was significantly impacted by ambient light conditions and surface characteristics. Additionally, they failed to detect lines when the ground clearance was more than a few millimeters.

In contrast, the TCS34725 color sensor demonstrated better performance, accurately identifying colors even at a distance of 15mm, after precise calibration. This provided the necessary ground clearance for the front of the robot. Only downside it has was, the sensor’s default sample integration time is 50ms introducing significant delay to the robot’s control loop. But we found out that it can be adjusted to 2.4ms, 24ms, 101ms, or 154ms, allowing for a trade-off between speed and accuracy. Given that our primary goal in this challenge is to complete all tasks rather than achieve the highest speed, the TCS34725 offers an excellent balance between speed and accuracy, making it the good choice for our application.

Also, we allowed the fact that better IR receivers and emitters from foreign reputed brands might be able to offer the performance we required, the cost of them would be higher than that of 5 colour sensors combined and we have to develop a sensor array circuit using them eliminating the capability of rapid prototyping unlike the plug and use capability of colour modules as they are using I2C for communication. (When making a colour sensor array these modules needed to address with an I2C multiplexer as this sensor does not come with a XSHUT pin)

As a side note, we opted against implementing a sensor array lifting mechanism in the final subtask, which would have eliminated the need for sufficient ground clearance in the front of the robot. We made this decision to avoid adding unnecessary mechanical complexity to our robot’s design.

### 2.2 VL530L0X ToF sensor

For wall detection, gate detection, and box height measurement, we selected the VL53L0X ToF sensor mounted on an SG90 servo motor. As it has a range of 3cm to 200cm, this sensor comfortably meets our requirements.

We decided against using ultrasonic sensors due to their lower accuracy compared to ToF sensors, larger size, and greater fluctuation in readings. While ToF sensors also exhibit some fluctuations, we successfully mitigated this issue by applying a moving average filter and threshold filtering, achieving highly accurate readings with an error margin of just ±3mm. This level of precision is more than sufficient for our goals.

Additionally, we opted not to use IR sensors for wall detection because, unlike ToF sensors, they depend solely on the intensity of the reflected IR light. This makes them susceptible to variations in surface color, condition, and ambient light, potentially leading to less reliable readings.

Also as this sensor have a XSHUT pin, we can integrate this into the I2C bus without needing to interfere with a multiplexer, reducing the complexity.

### 2.3 GY-271 (HMC5883L) 3 axis Magnetometer

After entering the rough terrain section, we will rely on this magnetometer sensor and wall detection from the 3 ToF sensors for navigation, as encoder readings may be unreliable due to potential slipping. The magnetometer can measure magnetic field intensities across different ranges, minimum range being ±1.3G while the maximum range being ±8.1G. Initially, we will use the lower range to maintain a constant heading based on the Earth’s magnetic field. If the readings exceeds the lower range due to the magnetic field present in the arena, the robot has the capability of switching to higher measuring range and follow the path where the magnetic readings get even higher and higher.

We did not explore alternative solutions, as this was the only viable option we found. We have tested the magnetometer for maintaining a constant heading on the XY plane using the Earth’s magnetic field. However, we still need to study how the readings are affected by an external magnetic field.

### 2.4 Side Note

Since all of these sensors support I2C communication, we can utilize a single I2C bus on the MCU, which simplifies wiring and reduce the number of pins required for the sensors.

Additionally, we are considering integrating an accelerometer and gyroscope, such as the BMI160 or LSM6DS3, depending on the accuracy of turn detection with encoder readings in the rough terrain.

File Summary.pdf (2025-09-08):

# Robot Design & Competition Strategy & Design Summary

Team Savitars
K.L.Gunathilaka (220197E), I.J.M.J. Sadaruwan(220542J), L.P.P. Pahasara (220439B), T.P.N.S. Peiris (220454P), M.P.L. Budvin (220077L)

September 28, 2024

## 1 Overall strategy

Initially the coin would be positioned on a electromagnet (KK P20/15 lifting solenoid) that is placed on the center of the robot. This will stay on until the coin drop.
The robot will employ array of five TCS34725 colour sensors for all the coloured & black,white line following tasks. Encoder readings will be used to maintain constant speed & detect the distances robot travel thus will be employed for task 1 for reading the white line code.
3 ToF sensors will be employed. 1 will be mounted facing front, on the gripper that is vertically moving and other 2 will be mounted on the sides of the robot. The front faced ToF will be used to detect the black, blocking wall in front of the coloured squares.
Colour sensor array will detect the tangled coloured lines withing 50ms each loop (24ms in the other regions as accuracy of the colours is crucial in this task).
In the task 5, white line segments following,after losing the white line, robot will move straight for some certain distance.In that period if the robot didn’t come across an line,robot will rotate and come back by small decrements of distances.
Robot will stop after detecting the white square, near the gate. Front ToF will be employed detecting the gate. The robot will keep the vertically movable front ToF at a constant height for 8 seconds. If the ToF isn’t blocked for atleast 1.5 seconds, then robot will move the ToF by 2cm vertically. This will be done until the gate is detected. After detecting the gate and making it confirmed by checking whether the reading is blocked for 5 seconds robot will move ahead as soon as it results in a unblocked ToF reading. (Distances, Periods are subjected to change)
The ToF sensor mounted on the gripper is also used to identify the heights of the box. The robot stops in front of each box at a constant distance, and the ToF sensor reads this distance.We then move the gripper upwards until the distance measurement changes.By noting the distance that the gripper have travelled when this change occurs, robot will determine height of each box For example, if the box is 10 cm, ToF distance reading will be blocked value, until we reach height of 10cm from the ground. The gripper has a vertical range of motion from 2.5 to 12.5cm. So this is feasible.
We use our front ToF sensor and parallel gripper to identify the distances and grab and lift the box. The same combination will be used to place the 5cm box in the chamber. The gripper is designed in a way that it can place the 5cm box in the 7x7 opening. After only grabbing the box inside half the length of the arms, robot will move forward until the box is completely inside the chamber and release the box.
After detecting the black stripes using the colour sensor array, the robot will enter the uneven terrain and will employ the side mounted and front faced ToFs to navigate without hitting the walls.Colour sensor array will be used to detect the black cross. As this sensor is cable of identifying colours accurately at a distance above 1cm, this sensor array will be placed in such a way that the robot has enough ground clearance. The robot will go to the center of that area following a rectangular spiral path using the distances to the walls obtained through the ToFs. Encoder readings would not be employed here as slipping can occur. This way the robot will cover the entire area and won’t miss the cross. After arriving at the cross, the robot will de-energize the solenoid and release the coin.

1

## 2 Robot mechanical design

### 2.1 Actuators

The MG90 servo motor will be used to drive the gripper across the vertical rack.SG90 servo will be used to open and close robot’s parallel gripper arms. 4 JGA 25-370 brushed DC motors with encoderswill be used to drive the robot. KK P20/15 solenoid will be used to grap and drop the coin.

### 2.2 Mechanisms

In our 2nd design iteration, robot employs 4 wheel design that let addressing and controlling each motor separately via 4 attached encoders and 2 dual motor controllers. The robot will utilize rack and pinion mechanism for its parallel gripper.The gripper arms has a very small thickness of only 4mm, enabling it to navigate tight spaces.With a maximum opening of 6.9cm, the gripper can grasp the 5cm box. Even while holding the box the combined width of the gripper arm (4mm) and the grasped box (5cm) adds up to 5.8cm, leaving enough space to pass through the 7cm x 7cm chamber opening.The gripper has a vertical range of 2.5cm to 12.5cm.

## 3 Sensors

We mainly use 5 x TCS34725 color sensor, 3 x VL530L0X Time-of-Flight sensors and will use an I2C multiplexer to address each of the TCS34725 sensor module as it doesn’t contain an XSHUT pin. Colour sensor array will be mounted on the front of the robot about 1.2cm from the ground. ToFs are mounted at sides and on the gripper. Applications of each sensor is mentioned in the overall strategy section.

## 4 Algorithms

- PD controller will be used to maintain constant speed and for line following.
- Rectangular spiral search will be used to navigate the uneven terrain. The robot will first turn 90 degrees and perform wall following until it can no longer proceed. It will then turn 90 degrees again and resume wall following. After completing one round of wall following at a certain distance, the distance threshold for wall following will be incremented by the robot’s wheel gap.The robot will then follow the walls at a greater distance, creating a rectangular spiral path to cover the entire area. This process will allow the robot to locate the black cross in the terrain.
- For maze navigation, the robot will first identify the unblocked colored cell. If the unblocked colored square aligns with the position of the box, the robot will navigate directly to that position from the second 120cm line, reverse back to the colored cell, and drop the box. If they don’t align, the robot will return to the position in the shortest path and pickup and reverse or go forward and drop the box at the aligned position with unblocked coloured squre. Then it will go to the 2nd 120cm line again and reverse back to the coloured cell and drop the box there.

2

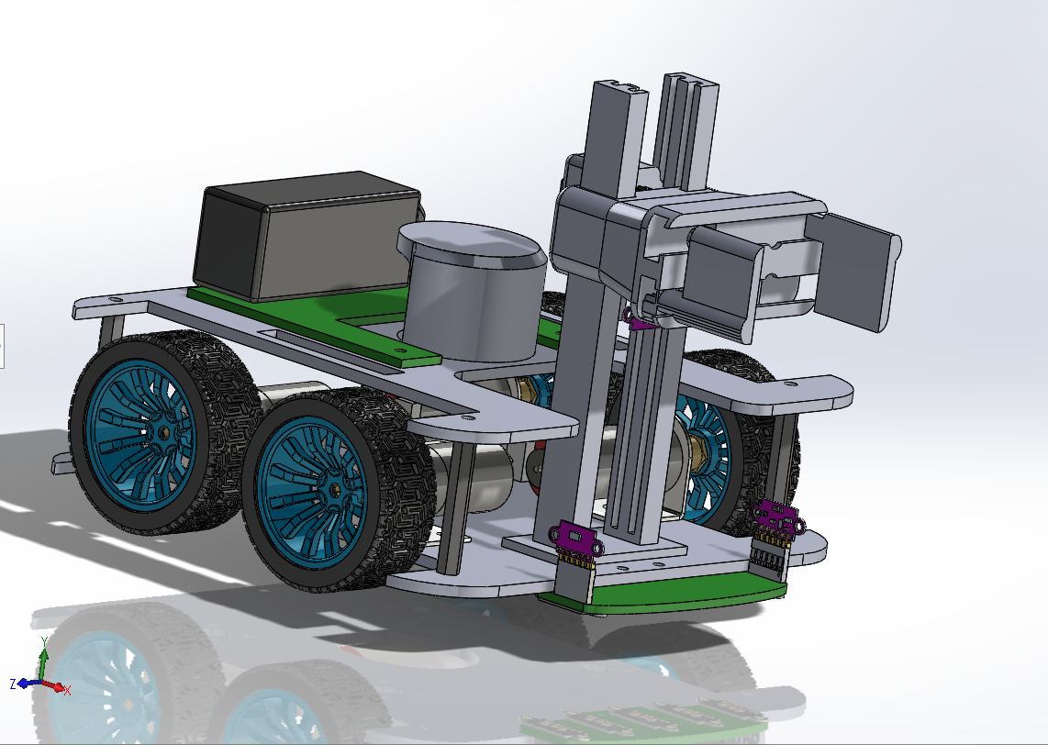
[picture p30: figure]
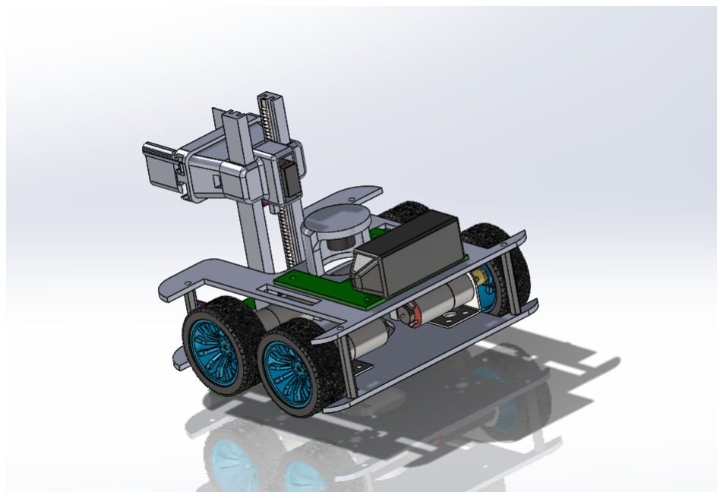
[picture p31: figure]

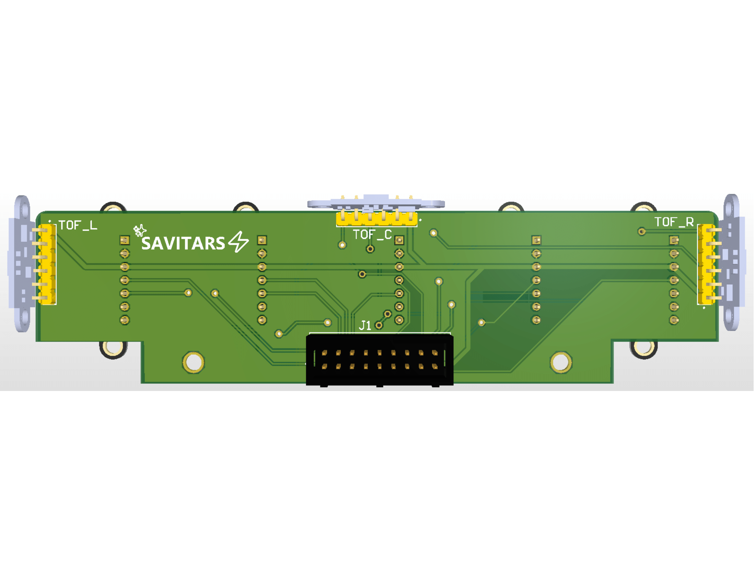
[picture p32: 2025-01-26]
Images/Job1-5.png

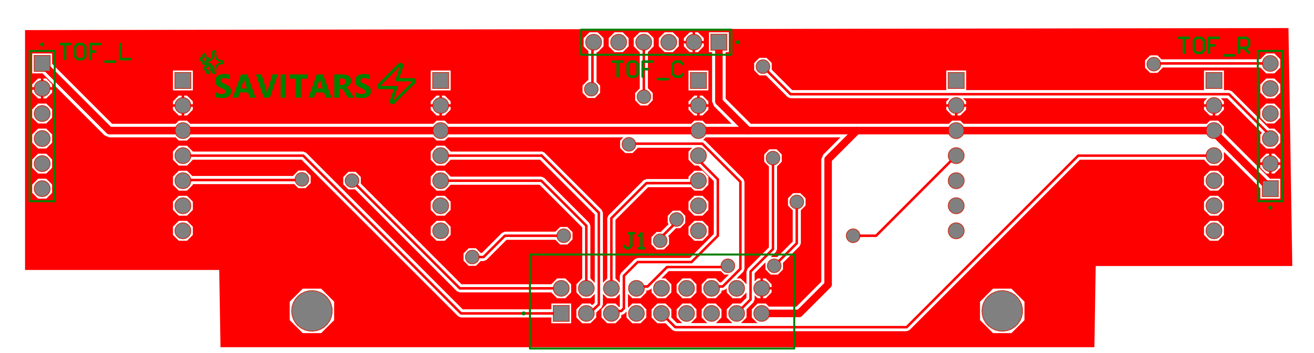
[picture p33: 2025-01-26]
Images/Job1-4.png

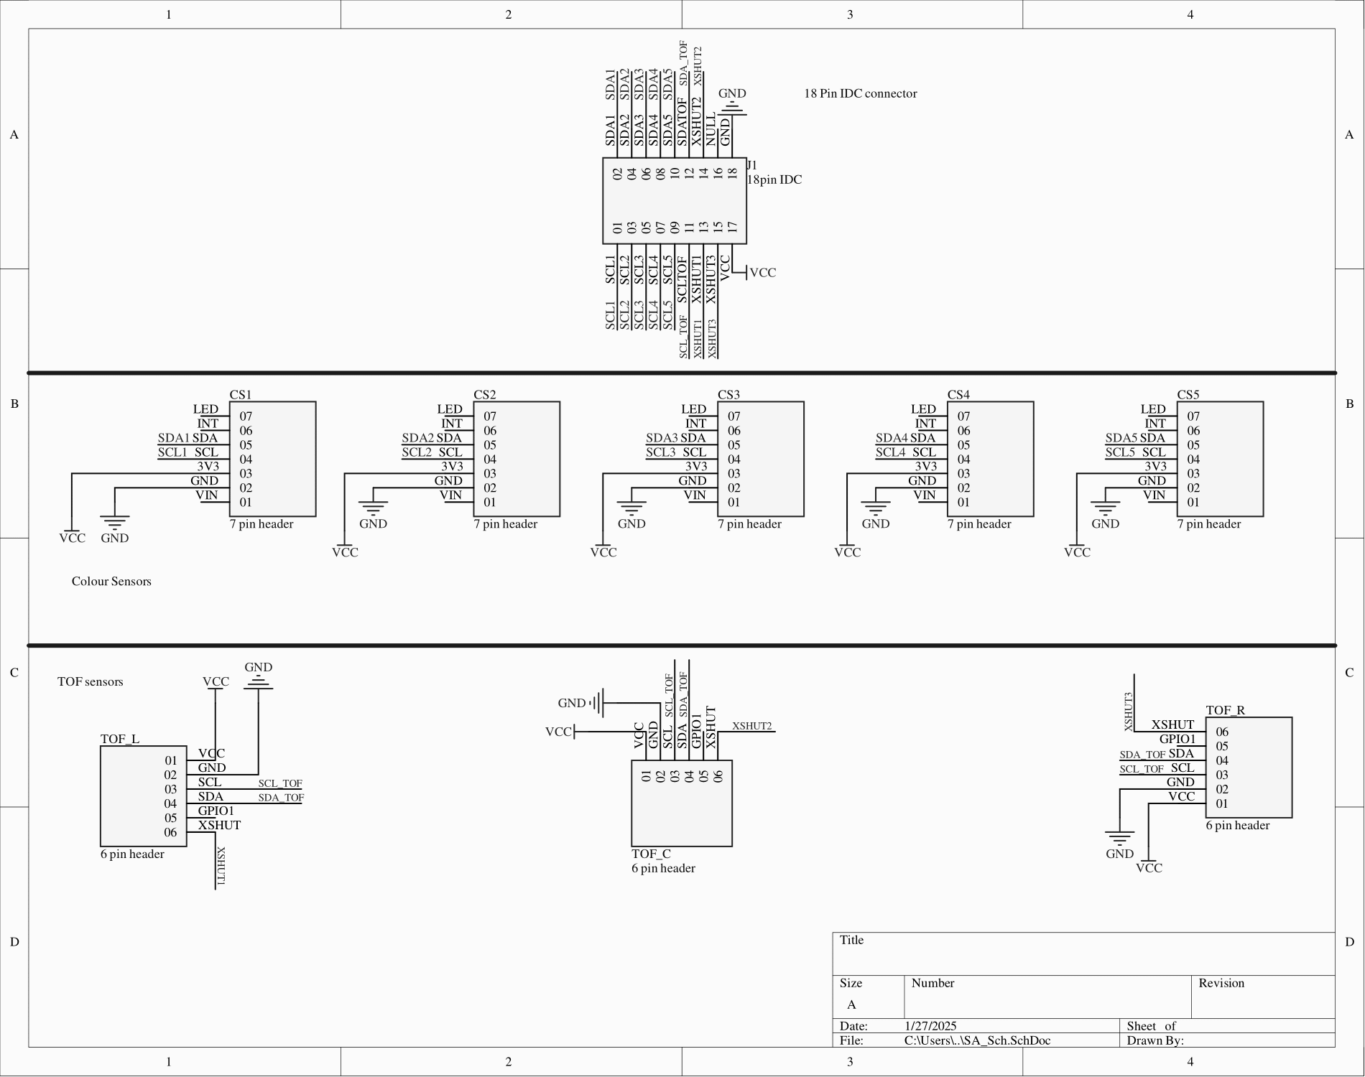
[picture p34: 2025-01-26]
Images/Job1-1.png

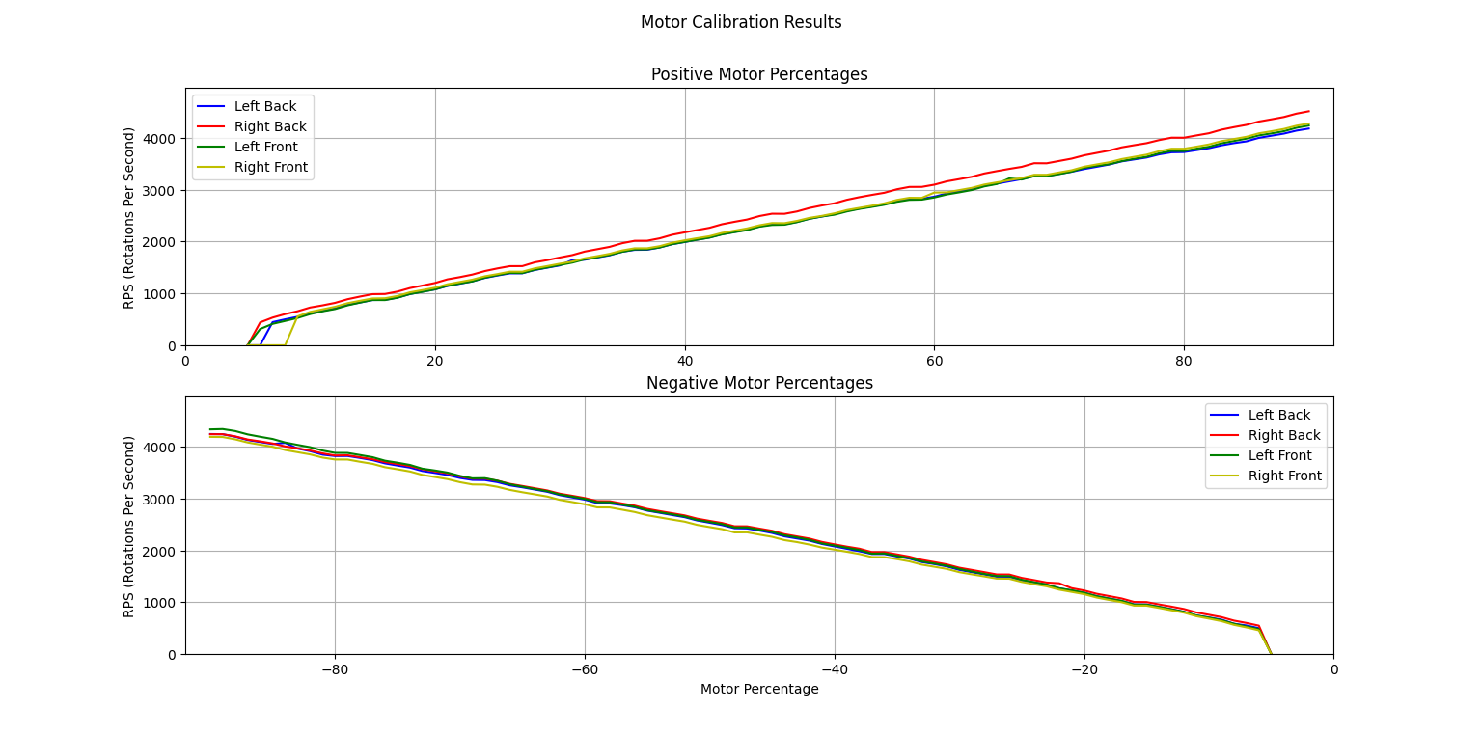
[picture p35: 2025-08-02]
Images/Figure_3.png

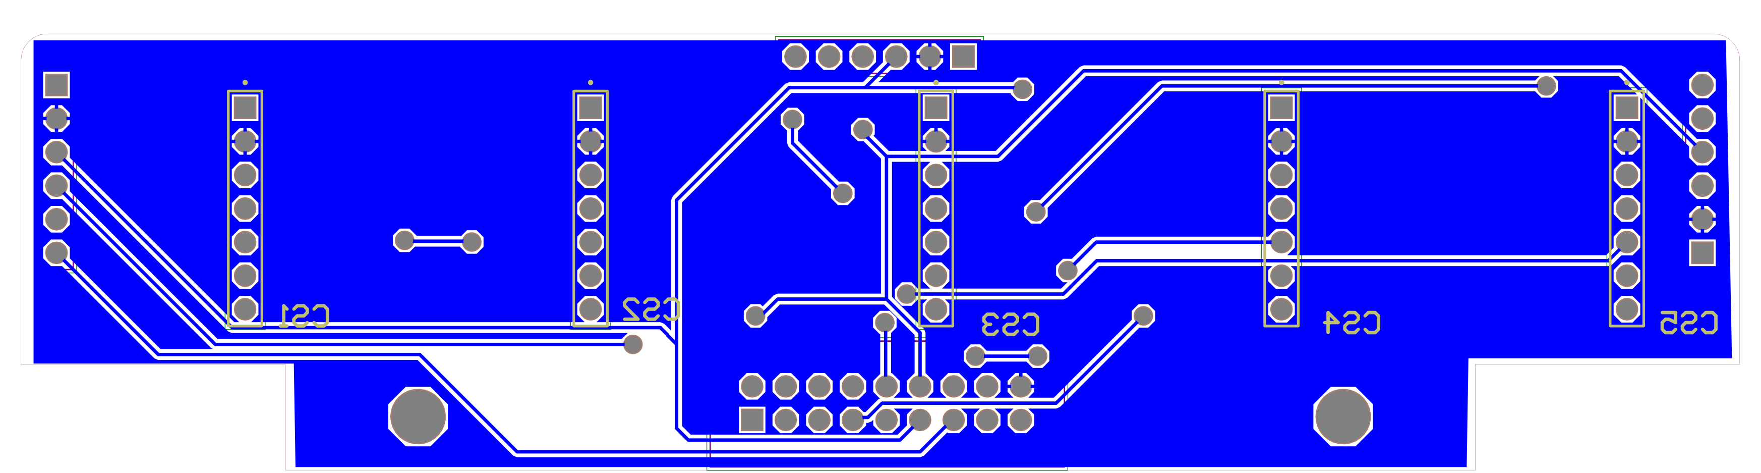
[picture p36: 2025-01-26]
Images/Job1-3.png

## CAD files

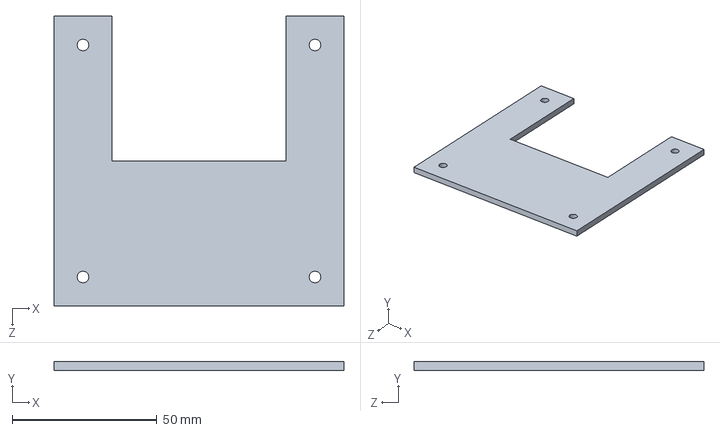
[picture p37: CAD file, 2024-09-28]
CAD/Design_V3/pcbMain.SLDPRT
100.0 x 3.00 x 100.0 mm

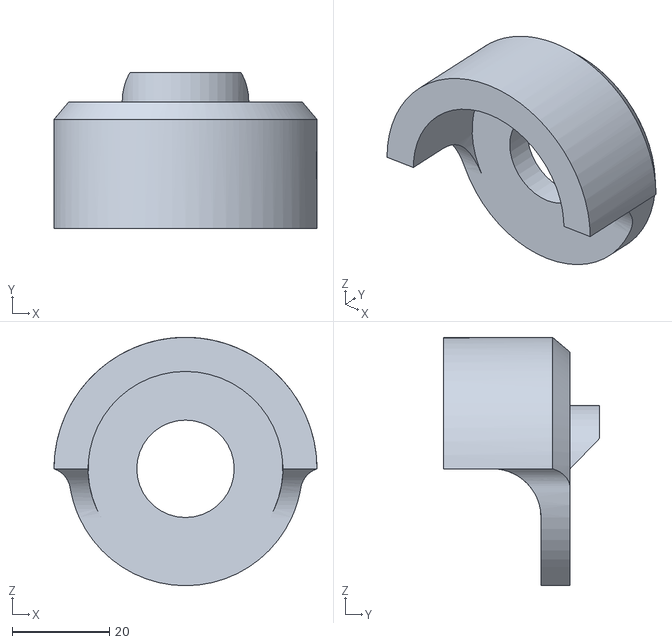
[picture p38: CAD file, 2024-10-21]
CAD/Design_V3/3DPrint/chassySTL/EMenclosure.STL
54.0 x 32.0 x 51.0

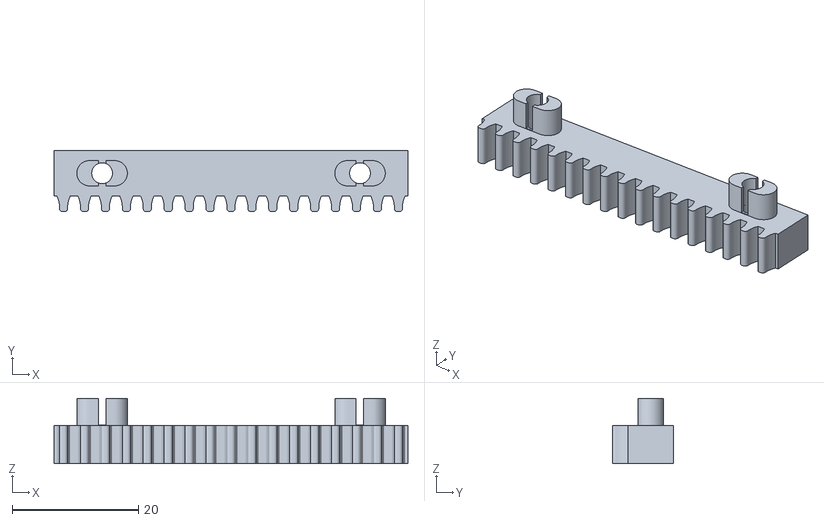
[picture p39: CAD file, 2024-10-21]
CAD/Design_V3/3DPrint/GripperSTL/gripperRack1_PrintTogether.STL
56.0 x 9.70 x 10.3

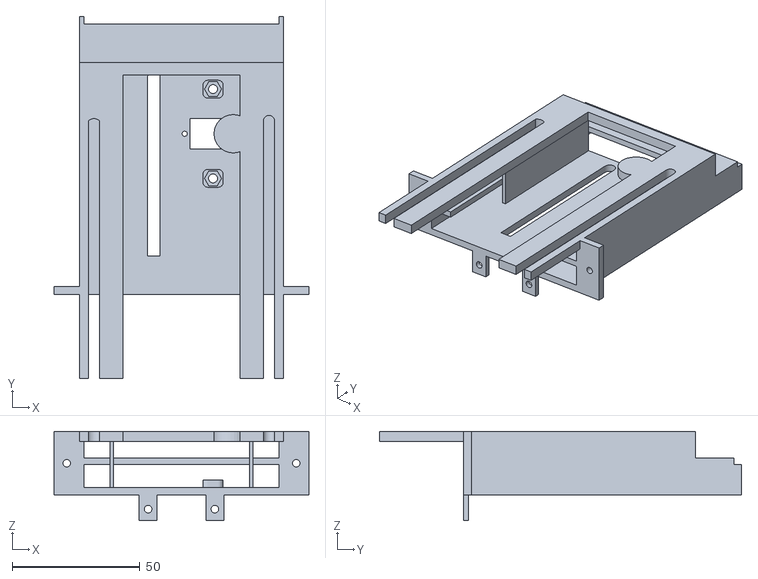
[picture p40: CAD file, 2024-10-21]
CAD/Design_V3/3DPrint/LiftSTL/forkliftBase.STL
100.0 x 142.0 x 35.0

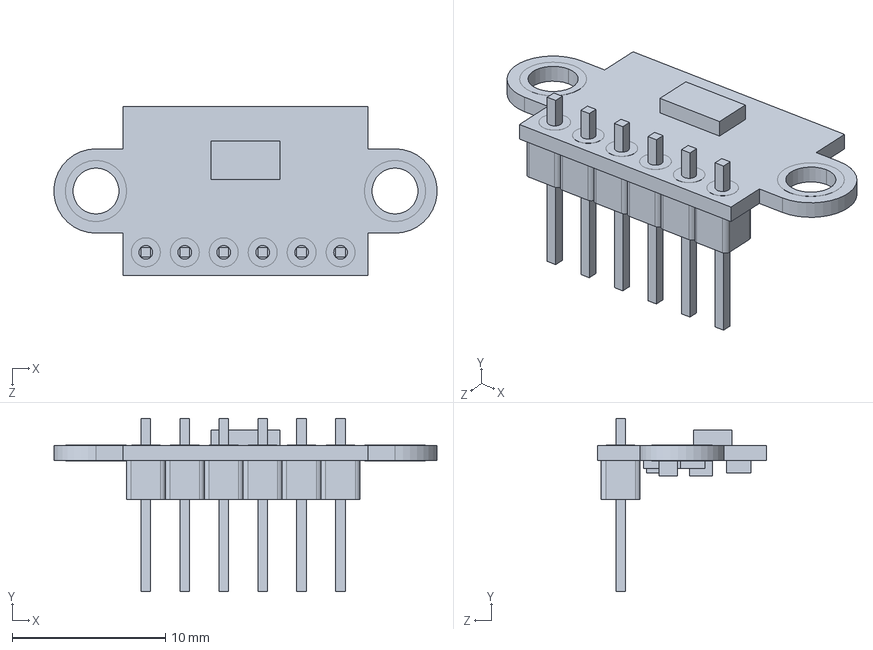
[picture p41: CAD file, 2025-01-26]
CAD/Design_V3/Gripper/vl53l0x.SLDPRT
25.0 x 11.3 x 11.0 mm

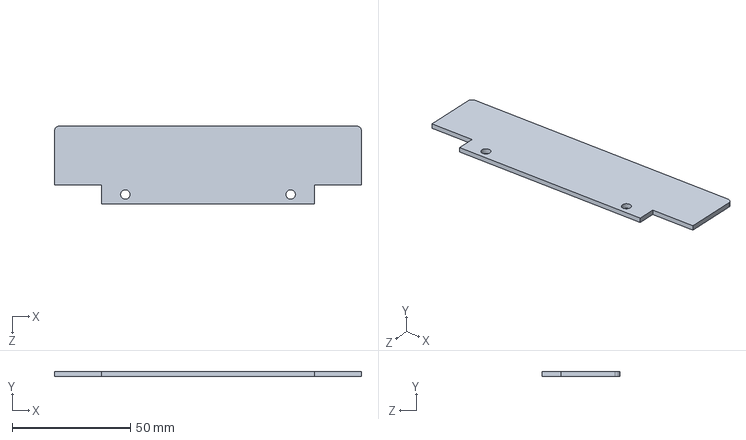
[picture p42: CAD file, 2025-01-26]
CAD/Design_V3/sensorPCB.SLDPRT
130.0 x 2.00 x 33.0 mm

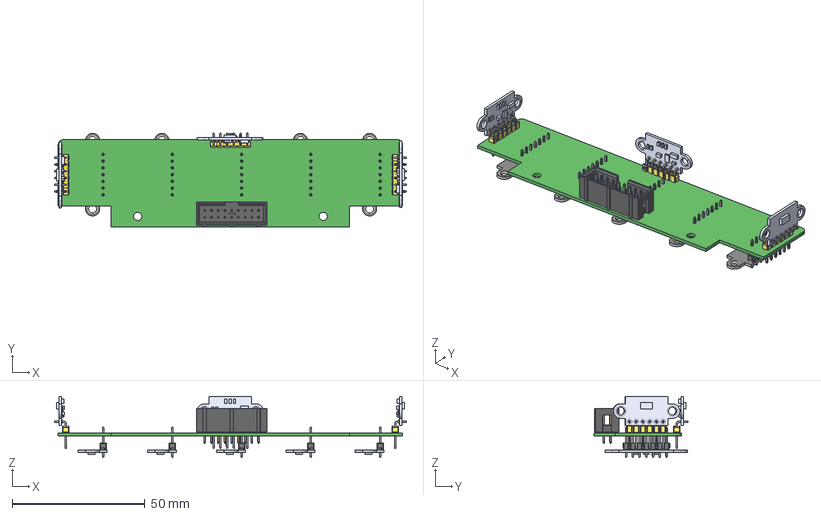
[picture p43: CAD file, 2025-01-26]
PCB/sensorArrPCB.step
132.8 x 35.5 x 23.0 mm
Straight Contact x 18
18-Pin Shrouded Header Body
DS1022_yellow_1x06p_100mil_TypeD_rev1.0 x 3
vl53l0x x 3
DS1021_black_1x07p_100mil_Type1_rev1.0 x 5
TCS34725_SMD v1 x 5
LED x 10
contact (2) x 10
contact x 10
contact (1) x 10

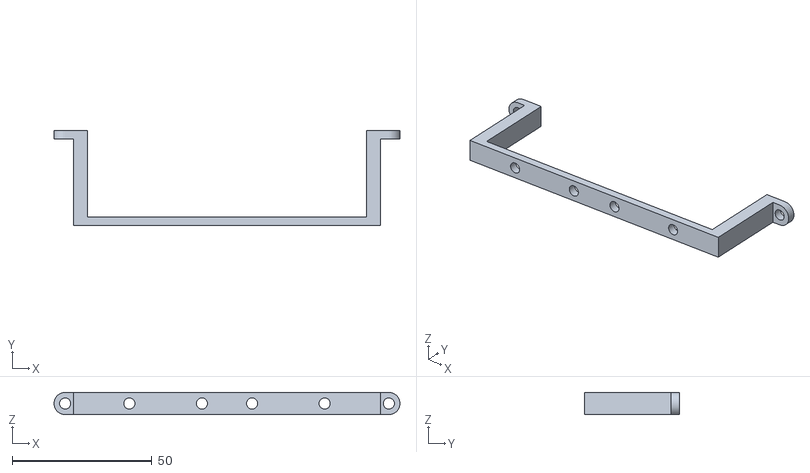
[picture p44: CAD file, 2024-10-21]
CAD/Design_V3/3DPrint/chassySTL/sensorArrayHolder.STL
124.0 x 34.0 x 8.00

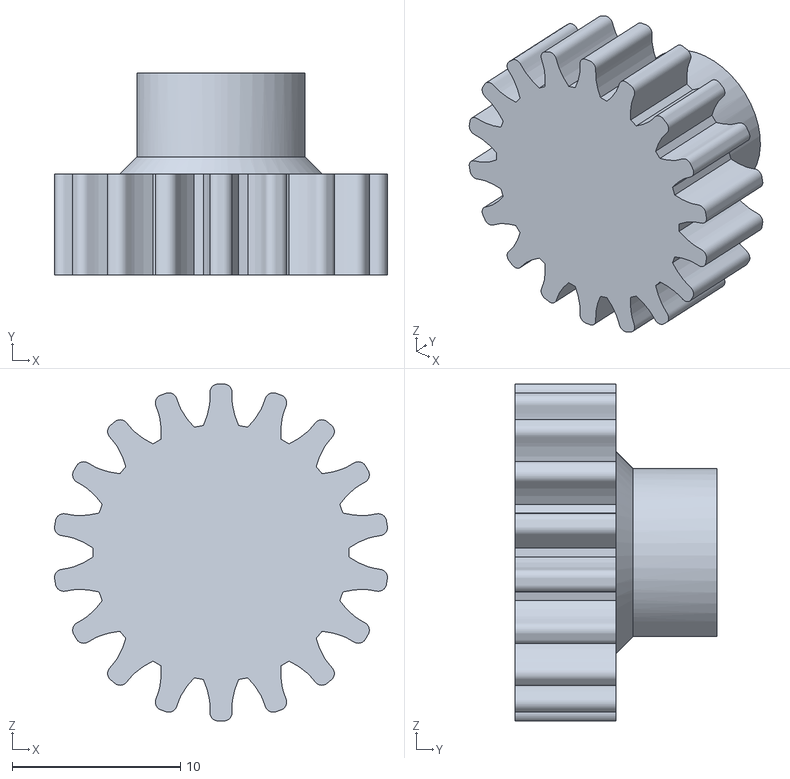
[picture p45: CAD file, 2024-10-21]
CAD/Design_V3/3DPrint/LiftSTL/forkLiftGear.STL
19.8 x 12.0 x 20.0

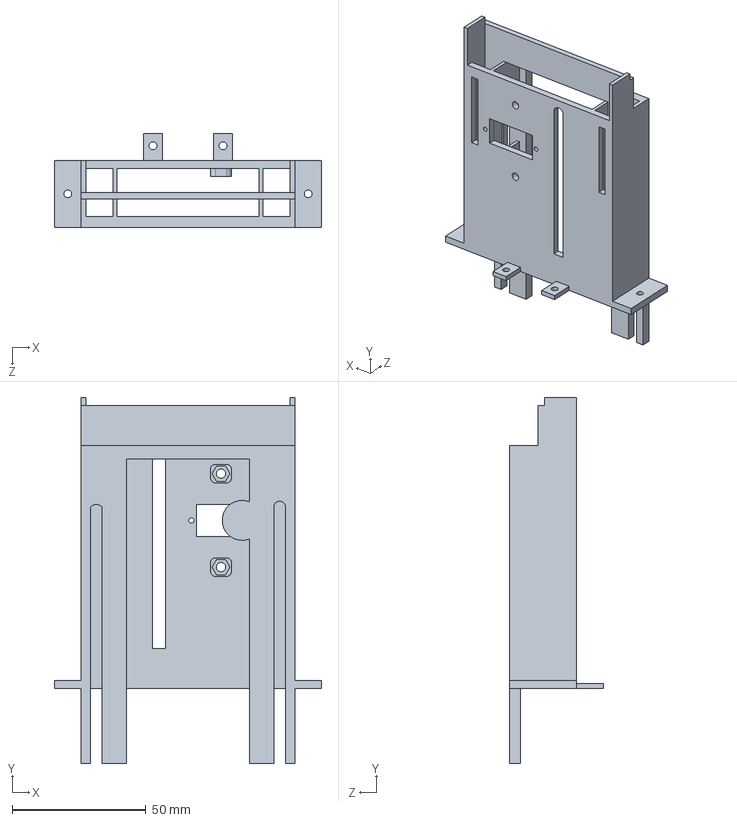
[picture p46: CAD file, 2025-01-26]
CAD/Design_V3/ForkLift/forkliftBase.SLDPRT
100.0 x 137.0 x 35.0 mm

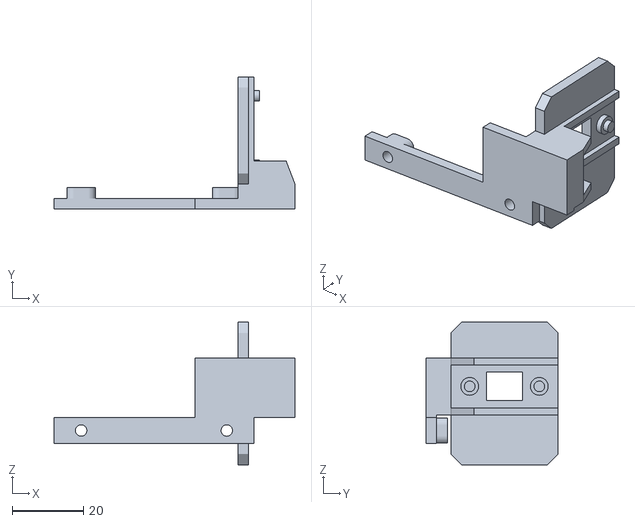
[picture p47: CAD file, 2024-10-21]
CAD/Design_V3/Gripper/GripperSTL/LeftJaw.STL
67.5 x 37.0 x 40.0

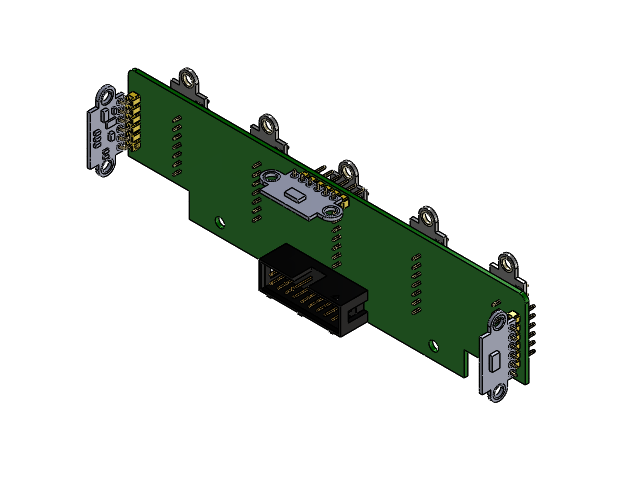
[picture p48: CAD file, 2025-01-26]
CAD/Design_V3/ForkLift/sensorArrPCB.SLDASM
Straight Contact.step x 18
18-Pin Shrouded Header Body.step
DS1022_yellow_1x06p_100mil_TypeD_rev1.0.step x 3
vl53l0x.step x 3
body.step x 10
LED.step x 10
contact (2).step x 10
contact.step x 10
contact (1).step x 10
TCS34725_SMD v1.step x 5
DS1021_black_1x07p_100mil_Type1_rev1.0.step x 5

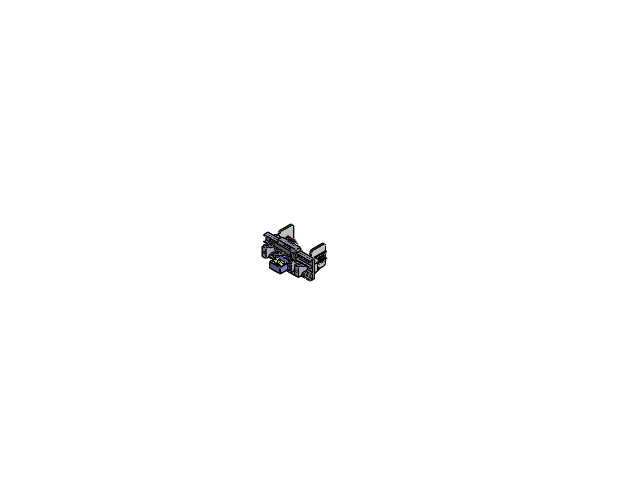
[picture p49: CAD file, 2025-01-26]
CAD/Design_V3/Gripper/gripper.SLDASM
gripperBase
gripperRack x 2
LeftJaw
RightJaw
vl53l0x x 3
SpurGear14_teeth
axis.step

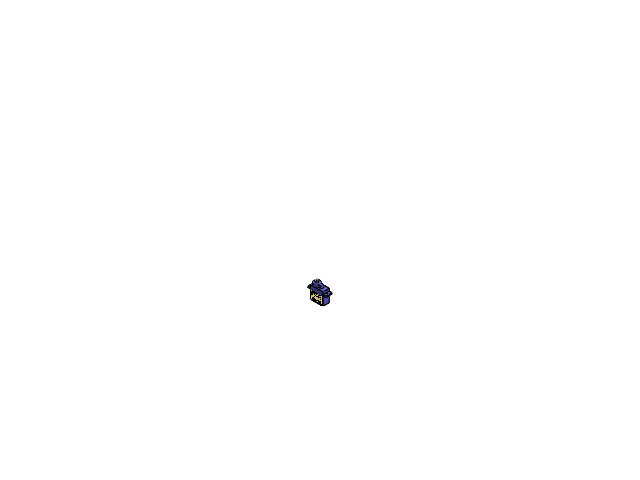
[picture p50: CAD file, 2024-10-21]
CAD/Design_V3/ForkLift/sg90servo.SLDASM
axis.step

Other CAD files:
CAD/Design_V3/Gripper/New sg90 micro servo.SLDASM
CAD/Design_V3/sensorArrayHolder.SLDPRT
CAD/Design_V2/ACE-X 1500mAh 4S Lipo Battery.iges
CAD/Design_V2/DC motor Bracket.SLDPRT
CAD/Design_V2/DS1022_yellow_1x06p_100mil_TypeD_rev1.0.SLDPRT
CAD/Design_V2/DS1022_yellow_1x06p_100mil_TypeD_rev1.0.STEP
CAD/Design_V2/DS1071-1x6.SLDPRT
CAD/Design_V2/DS1071-1x6.STEP
CAD/Design_V2/EM.SLDPRT
CAD/Design_V2/EMenclosure.SLDPRT
CAD/Design_V2/Elektromagnet.ipt
CAD/Design_V2/JGA25-370 DC12V350RPM.SLDPRT
CAD/Design_V2/Motor Driver.SLDPRT
CAD/Design_V2/NewGripper/Gripper.SLDASM
CAD/Design_V2/NewGripper/Metric - Rack-spur - rectangular 0.9M 20PA 5.5FW 2PH 51L---SAll.SLDPRT
CAD/Design_V2/NewGripper/SG90.SLDPRT
CAD/Design_V2/NewGripper/front_rail_base.SLDPRT
CAD/Design_V2/NewGripper/gripper_base.SLDPRT
CAD/Design_V2/NewGripper/gripper_finger.step.SLDPRT
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

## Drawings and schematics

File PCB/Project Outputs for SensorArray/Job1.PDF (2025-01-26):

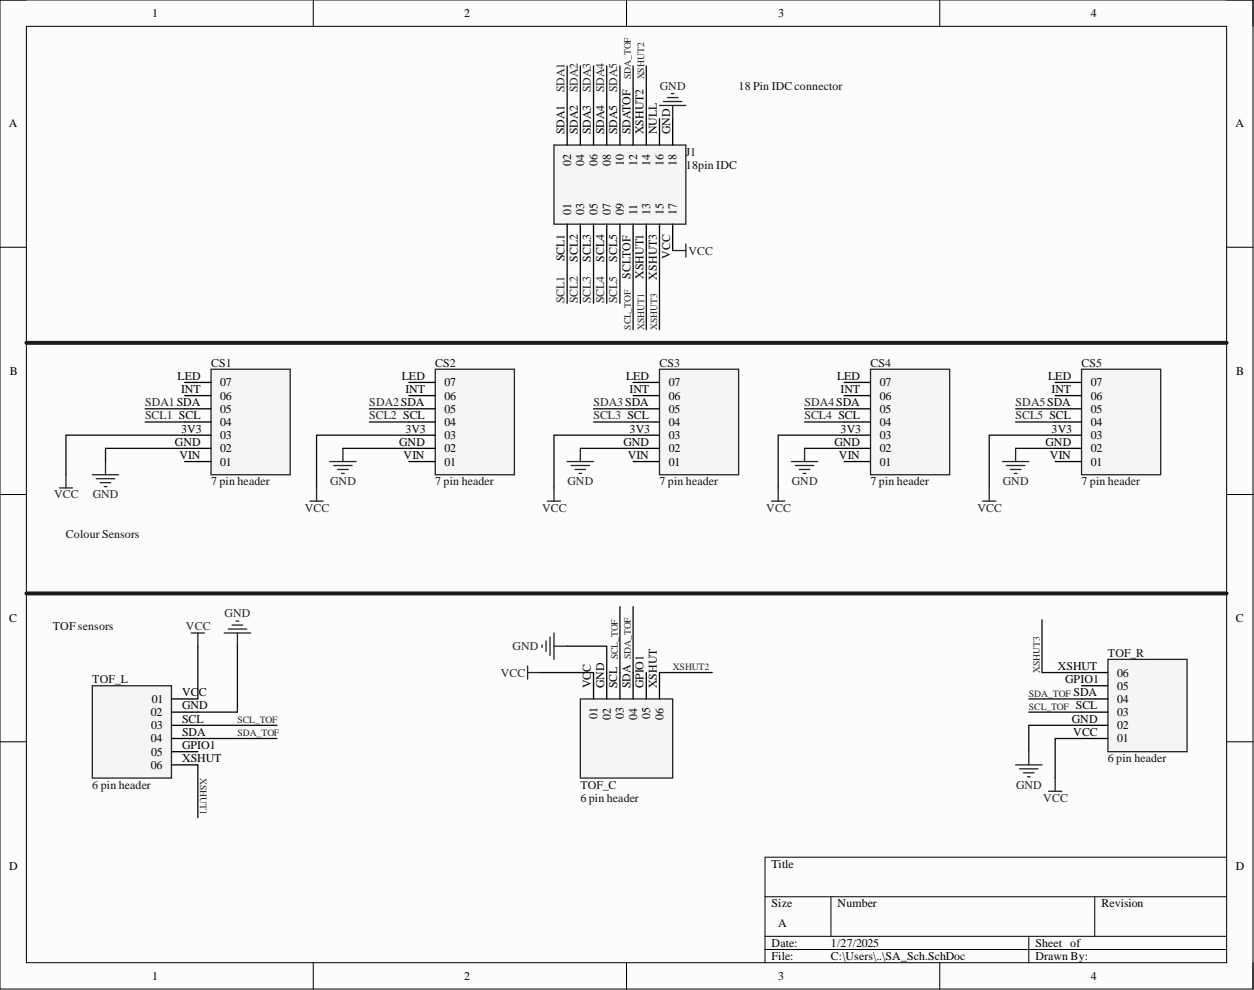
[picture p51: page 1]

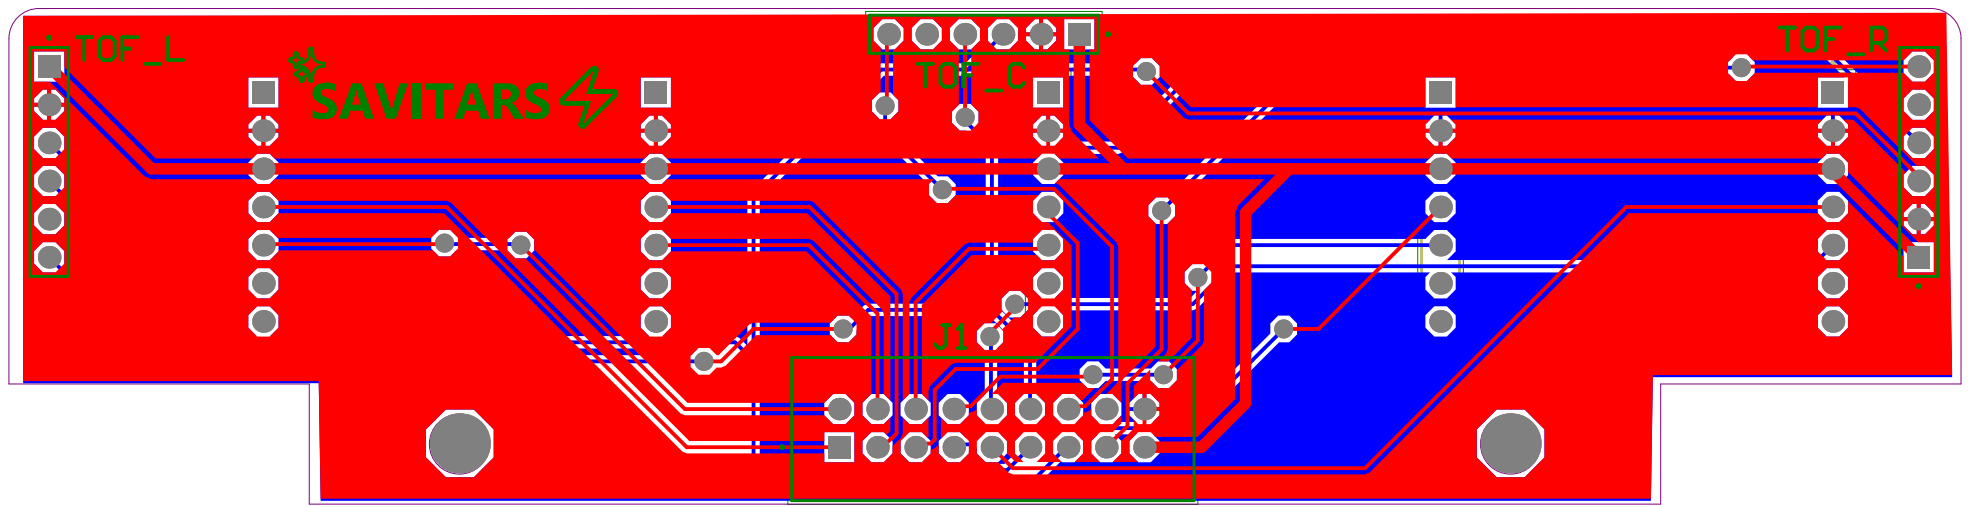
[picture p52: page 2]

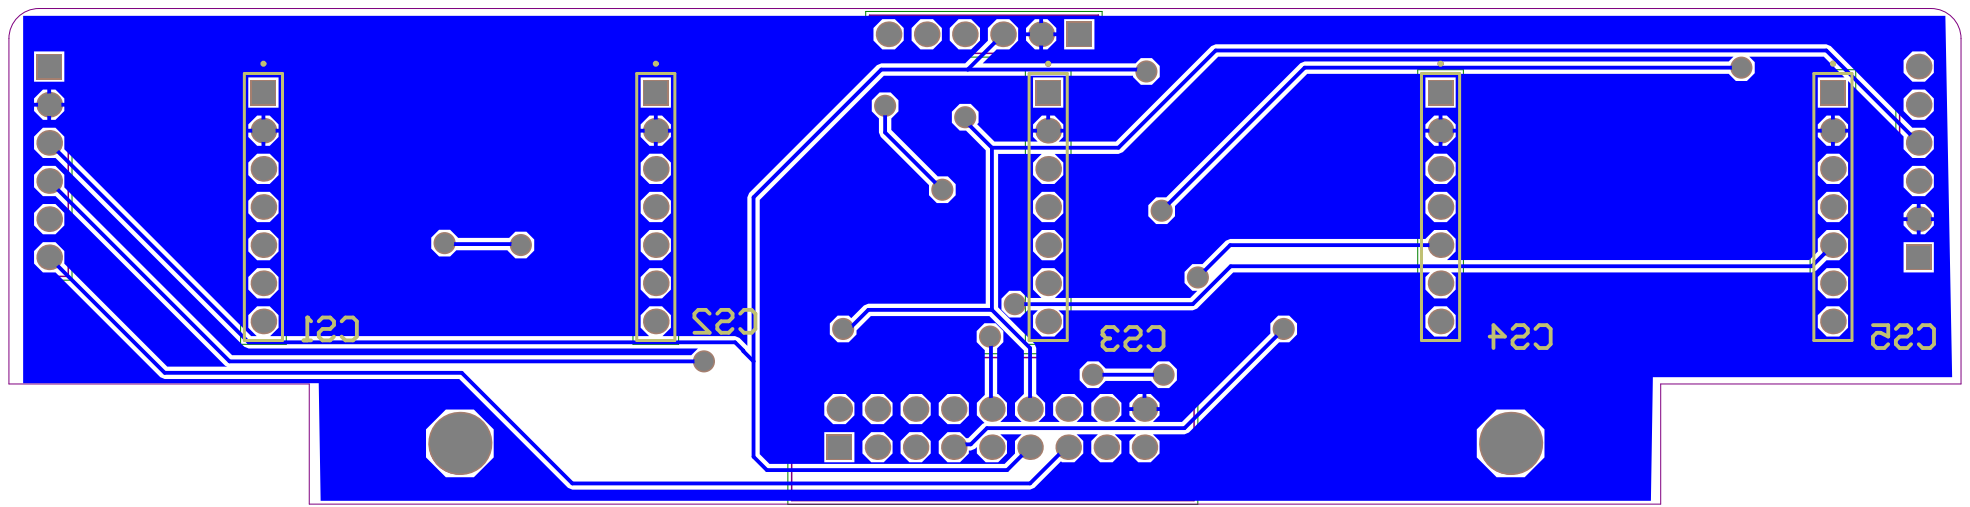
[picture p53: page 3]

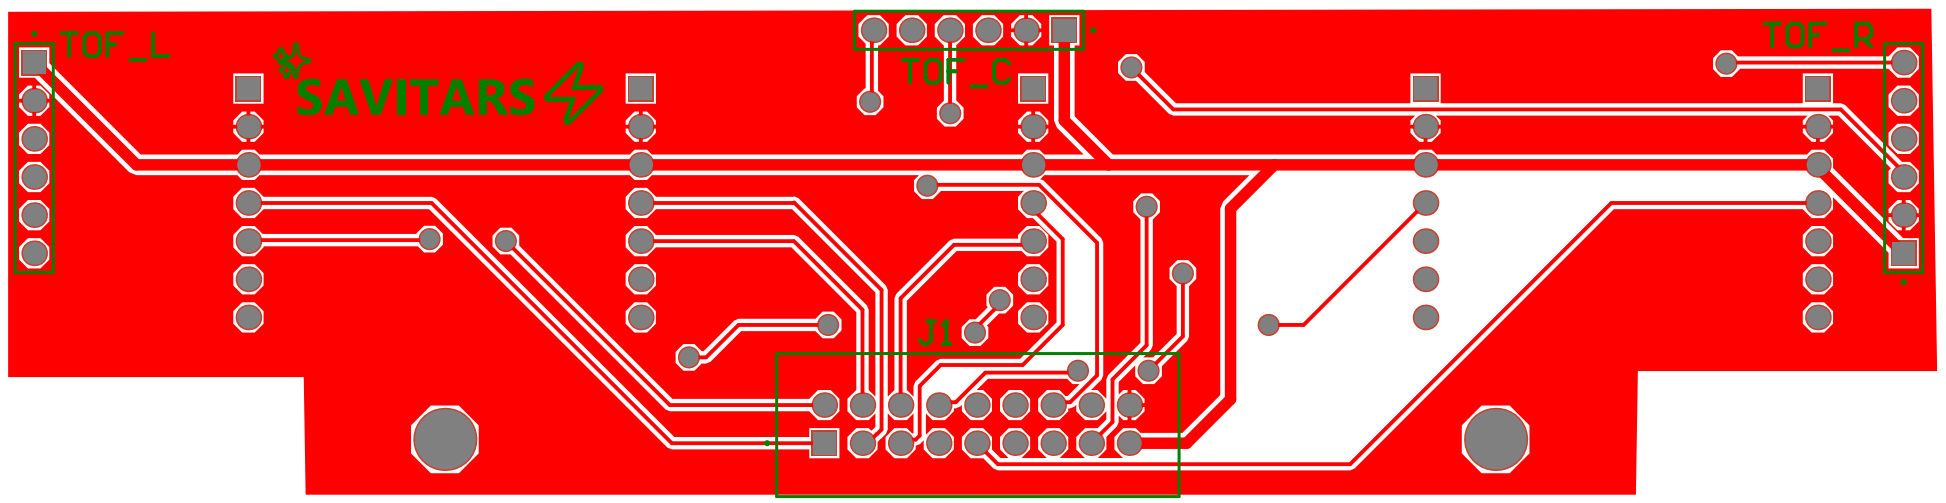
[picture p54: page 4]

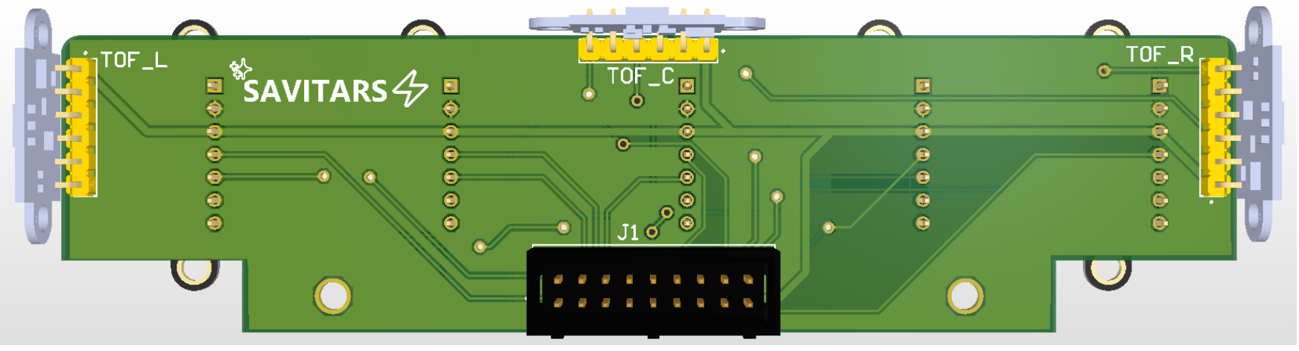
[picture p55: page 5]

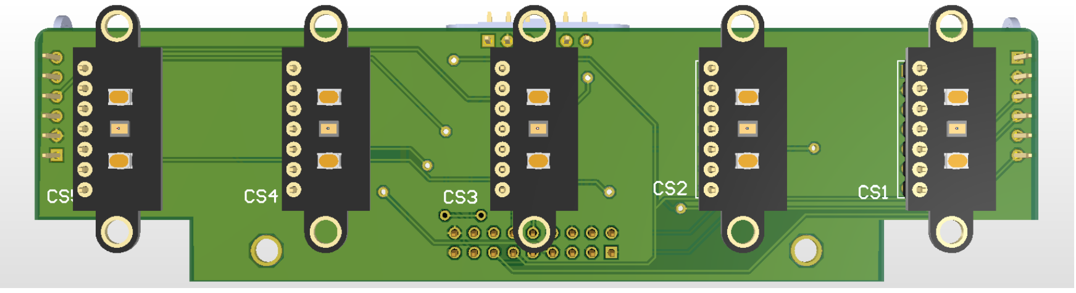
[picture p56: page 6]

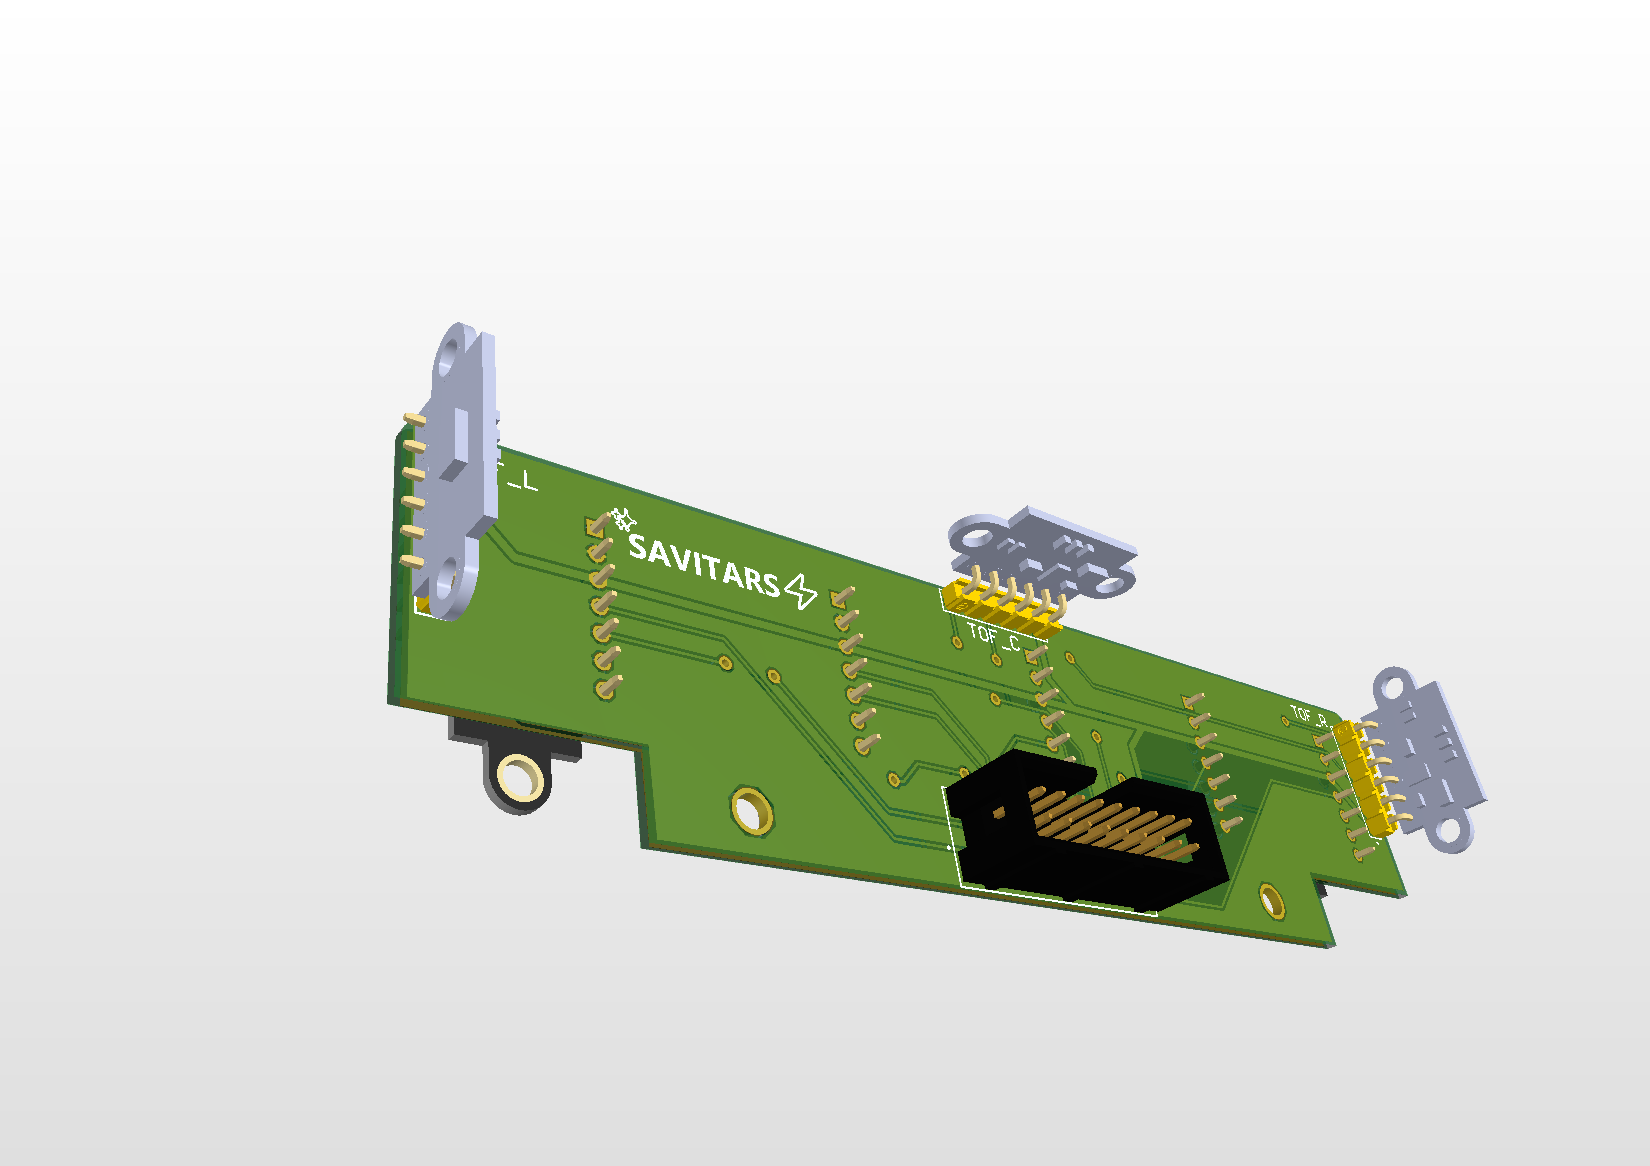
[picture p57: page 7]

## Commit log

2024-09-20 Some errors exist. need to fix them before proceeding
    [3MM联轴器.SLDPRT, 65mm蓝色轮胎总装-实际外径68mm.SLDASM, ACE-X 1500mAh 4S Lipo Battery.iges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]
2024-09-28 final design
    [EM.SLDPRT, EMenclosure.SLDPRT, Gripper.SLDASM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]
2024-10-21 added final version. printed and tested
    [2bases.SLDDRW, 2basesLaserCut.DXF, 3MM联轴器.SLDPRT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]
2025-01-26 added pcb
    [2bases.SLDDRW, 2basesLaserCut.DXF, 3MM联轴器.SLDPRT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]
2025-01-26 removed pcb submodule
    [SA_PcbLib.PcbLib, SA_Sch.SchDoc, SA_SchLib.SchLib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]
